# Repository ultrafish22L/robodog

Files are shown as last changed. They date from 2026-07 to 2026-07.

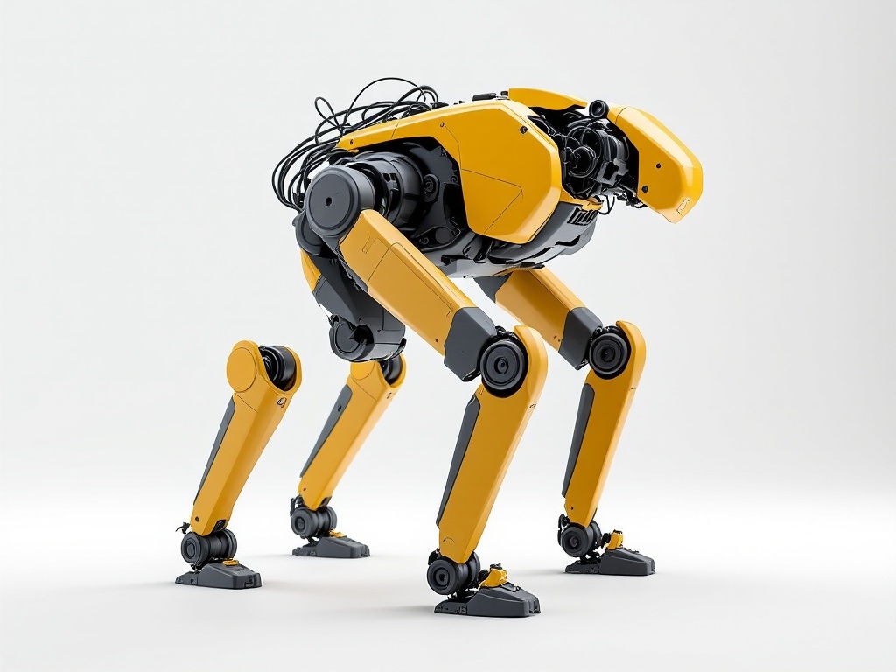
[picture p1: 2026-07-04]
ref/spot_ref_01.jpg

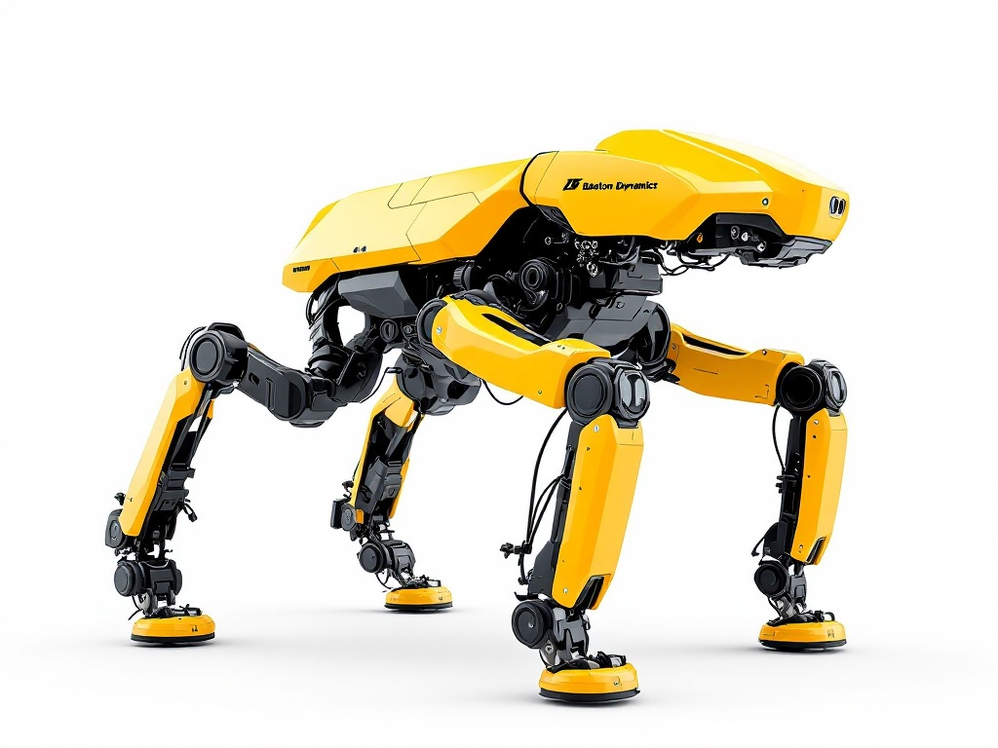
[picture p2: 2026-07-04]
ref/flux_side_b.jpg

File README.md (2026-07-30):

# Robodog — custom 3D-printable micro-servo quadruped

A parametric, 3D-printable quadruped ("Spot-mini") — a **fully custom design** (Boston Dynamics
Spot and the SM3 Spot-Micro were visual **references only**; no external mesh is used). Driven by
**12 micro-servos, 3 per leg** (knee = **MG90S** metal-gear, single-shear; the rest SG90-class).
Geometry is generated in **FreeCAD 1.1** by Python `Part` scripts — there is no saved `.FCStd`;
running the scripts rebuilds and re-exports everything.

> **Status — FIRST PRINTABLE PROTOTYPE (2026-07-30).** The v9 canonical set (11 STLs below) is
> watertight/manifold and slicer-ready for a Bambu **X1C** (256³ bed). See `robodog.md` (design
> bible + session log) for the full history and the latest `### Update`.

## Design (v9)
- **Direct-drive knee** (no linkage): the tibia bolts straight to the knee servo horn. ~200 mm dog,
  frame X ±103 mm.
- **Open truss frame** (`framemin.py`) with a central Y=0 wall, rim rails, 4 corner blocks, and two
  Ø16 splay-pin collars ~3 mm proud fore/aft. Carries the body snaps + alignment pegs.
- **One-piece snap-on body** canopy (`part_body.py`): single-feature head/rump, open belly over the
  trunk, form-fit hip openings, a crown-spine stiffener rib. Held by **lateral detent nubs + vertical
  alignment posts + central-wall pegs + collar-grip rings**.
- **Servo-horn receivers** are embedded (`horns.py`): the **arm** horn is the canonical print — the
  real OEM horn mesh (`servos/hornarm.stl`) is cut into the coxa/femur/tibia so the actual horn
  drops in at a print pause. (`mesh`/`round` variants available via `--horn=`.)
- **Printed screw-in splay pin** (`framemin.py` → `sm3sg90_pin`): Ø7.8 pilot + P2.0 thread mating
  the collar bore + a slotted Ø13 head. Print ×4.

## Canonical print set — 11 STLs (`stl/sm3sg90_*.stl`)
| STL | qty | script | notes |
|---|---|---|---|
| `sm3sg90_v9_frame` | ×1 | `framemin.py` | open truss, ~111 g |
| `sm3sg90_body` | ×1 | `part_body.py` | snap-on canopy |
| `sm3sg90_coxa` + `_mir` | ×2 ea | `coxablock.py` | L/R chiral, arm horn |
| `sm3sg90_coxa_cover` + `_mir` | ×2 ea | `coxablock.py` | femur-hip bearing face |
| `sm3sg90_v9_femur` + `_mir` | ×2 ea | `legflat_v9.py` | arm horn |
| `sm3sg90_v9_tibia` + `_mir` | ×2 ea | `legflat_v9.py` | arm horn, direct-drive |
| `sm3sg90_pin` | ×4 | `framemin.py` | screw-in splay pin |

All rigid PLA/PETG/ASA. **Bought:** 12 micro-servos, 8× 688 + 4× 684 bearings, M2 screws, electronics.

## Build / regenerate
Scripts `exec` each other into shared globals (never `import`). Run **headless** (GUI-independent):
```bash
"C:/Program Files/FreeCAD 1.1/bin/freecadcmd.exe" -c "exec(open('part_body.py').read())"   # coxa+cover+frame+body+pin
"C:/Program Files/FreeCAD 1.1/bin/freecadcmd.exe" -c "exec(open('legflat_v9.py').read())"  # femur+tibia (+mirrors)
```
`part_body.py` chains `dog14.py → dog13.py, coxablock.py, framemin.py, legflat_v9.py`. For the live
assembly view, run `dog14.py` in the FreeCAD GUI (frame + 4 legs + coxae + pins + body). Add
`--horn=mesh|round` to regenerate a horn variant.

## Key files
- **`dog13.py`** + its modules (`dogcommon`, `part_femur`, `part_tibia`, `part_boot`, `part_shoulder`,
  `part_frame`, `part_dummies`) — base geometry, the measured joint/splay axes, servo-mesh cutter.
- **`legflat_v9.py`** (leg, spec `LEG_SPEC.md`), **`coxablock.py`** (coxa, spec `COXA_SPEC.md`),
  **`framemin.py`** (frame + pin), **`part_body.py`** (body), **`horns.py`** (horn receivers),
  **`dog14.py`** (assembly + clearance gates).
- **`control/`** — the all-Python control/sim stack (URDF generated from the CAD axes; PyBullet, gait,
  poses). See `control/README.md`; `robodog.urdf` is regenerated by `control/gen_urdf.py`.
- **`robodog.md`** — the design bible + session log (**read the latest `### Update` to resume**).
- Auto-memory (loaded each session): `~/.claude/projects/C--ultrafish-robodog/memory/`.

## Gotchas (the ones that bite)
- Every printable part must be a **single watertight solid** (single shell for the hollow body — a
  trapped void isn't printable). Re-run the clearance gates after any change.
- STL export via `MeshPart.meshFromShape` (not `Shape.exportStl`); gate on watertight + manifold.
- The full chain in the **GUI exceeds the 90 s MCP RPC cap** (coxablock mesh booleans) — build
  headless via `freecadcmd`, or run `dog14` in the GUI and let the doc finish on the GUI thread.
- `servos/` is large local reference (gitignored) — but `servos/hornarm.stl` is force-tracked because
  `horns.py` reads it at build time.

## Known open items
- Collar grip is a light press (0.2 mm), not a click-into-groove snap — tune if wanted.
- Blade **width** in the arm horn embed and a few servo fits are still bench-verify items.
- `pamphlet.html` / `robodog.pdf` are the **old-design** assembly manual (generator removed) — stale.

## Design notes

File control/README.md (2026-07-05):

# robodog — control software

All-Python control + simulation for the SG90 quadruped, **generated from the CAD** (`../dog13.py`).
Runs headless in [PyBullet]; the same kinematics + gait code is intended to run on a Raspberry Pi +
PCA9685 driving the 12 SG90 servos (sim → real by design — only the bottom driver swaps).

## Setup
```
py -3.13 -m venv .venv
.venv\Scripts\python -m pip install pybullet numpy trimesh pillow
```

## Modules
| file | what |
|---|---|
| `kinematics.py` | per-leg 3-DOF FK/IK in the body frame; anchors (SP/HP/K) come from the CAD. `Leg.ik(target, warm=)` |
| `gen_urdf.py` | writes `robodog.urdf` from the axis constants + the 17 exported STLs + trimesh inertials |
| `poses.py` | named static poses (stand/sit/lie/paw) as body-frame foot targets + a self-collision validator |
| `gait.py` | static **crawl** gait + a PyBullet dynamics runner (`run()`) that measures forward travel + uprightness |
| `explore.py` | random → hill-climb search over gait params, scored by sim rollout; writes `best_gait.json` |
| `viz.py` | load the URDF, verify FK vs kinematics, render poses |

## Quick start
```
.venv\Scripts\python gen_urdf.py     # build robodog.urdf
.venv\Scripts\python viz.py          # FK check + zero/stand renders
.venv\Scripts\python poses.py        # pose library + validation montage
.venv\Scripts\python gait.py         # crawl walk in sim (filmstrip)
.venv\Scripts\python explore.py      # search for a better gait
```

## Verified (2026-07-04)
- Per-leg FK matches PyBullet to 0.00 mm on all 4 legs.
- Poses solve at ~0 mm IK residual; collision validator catches forced self-collisions.
- Crawl gait walks **forward, upright, without falling** under gravity.

## Roadmap
- [x] 1 model + FK/IK  [x] 2 poses + validator  [x] 3 crawl gait  [~] 4 gait search
- [ ] 5 glTF/three.js web viewer  [ ] 6 `hardware.py` — Pi/PCA9685 PWM + servo calibration

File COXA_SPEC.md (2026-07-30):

# COXA SPEC — canonical source of truth

**Read this first before touching the coxa. Edit it IN PLACE** — it is a spec (current state),
not a changelog. Only the short decision log at the bottom records *why*.

Built by `coxablock.py` (subtractive-from-block). Supersedes `dog13.py`'s `shoulder()` **for
printing**; `shoulder()` is still the live `SH` used by the assembly/gates/renders and by
`frameblock.py`, so it stays until coxablock replaces it there too.

---

## Parts — 2 printable, ×2 chirality = 4 STLs in `/stl`

| STL | vol mm³ | role |
|---|---|---|
| `sm3sg90_coxa.stl` + `_mir` | ~18.5k | the **solid block**: servo1 pocket, tab channel, wire slot, splay bearing cup, splay horn — **R17 solid end housings (2026-07-29, un-did the R16 barrel strip; solid walls on the servo ±X faces)** |
| `sm3sg90_coxa_cover.stl` + `_mir` | 4238 | black snap cover: closes the +Y mouth, cages the servo, **is the femur bearing face** (was 5433; shrinks with the seam profile) |

All four (plus the `_spline` pair, coxa 9152) verified on disk: watertight, manifold, no self-intersections —
the export now runs export.py's `repair_clean` write-re-read loop, and the coxa build FAILS (no cover STL)
if the cover diverges from the seam profile.

### Horn variants — 3 modes (`--horn=mesh|round|arm`) via `horns.py` (user 2026-07-28)

The −X splay horn end is built in one of THREE modes via the shared **`horns.py`** (`exec`'d, not imported;
`horn_void(COXA,(hrn_face,SPY,SPZ),(1,0,0),(0,0,1),MODE,floor=0.5,mesh_len=HRN_DT+HRN_ST,m2=None)`). Back-compat:
`embed`→`round`, `spline`→`mesh`. **The COXA alone differs; the cover is horn-independent, exported once (canonical
round run only).** The block genuinely rebuilds per mode (R_END + the chamfer envelope depend on the horn footprint).

| mode | what the −X horn end gets | STL names |
|---|---|---|
| `round` (canonical) | O20 disc chamber (1.5) + O7 spline hole + roof (**3.5mm WSRV wall**) — OEM round horn dropped in at a print pause | `sm3sg90_coxa[_mir].stl` — the **canonical** names |
| `mesh` | printed 23T female spline (prints in place, no hardware) | `sm3sg90_coxa_mesh[_mir].stl` |
| `arm` | O7.6 hub pocket (4.25) + arm through-slot (12.5, ±Z so it clears the cover seam) + roof (1.75mm to servo1); M2=None (would breach servo1) | `sm3sg90_coxa_arm[_mir].stl` |

- **PAUSE-LAYER (embed): −X face DOWN on the bed, pause at 0.5mm** (round: at the disc-chamber floor / arm: at the
  arm-slot shelf), drop the OEM horn hub-down, resume — the WSRV wall roof captures it.
- `round` (canonical) must keep the exact filenames: **`control/gen_urdf.py` requires `stl/sm3sg90_coxa_mir.stl`**.
  `mesh`/`arm` write suffixed alongside. Verified watertight/manifold/1-solid + adversarial-clean (wf_6e2a558c).
- The receiver is **parametric, not a mesh**. A donor STL (`MicroServo_9g_Gear_Base_V4`) was tried and
  abandoned: `makeShapeFromMesh` gives one face per facet, and at 1448 facets the fuse ran >196 s and
  timed out the GUI. Decimating to 970 facets **inverted the normals** (negative volume → fused to
  nothing); harmonising fixed the sign but left 6% of the volume with the teeth gone. Parametric teeth
  build in ~40 s and are exact. Do not reach for the mesh again.
- **`SPL_TEETH = 23` must equal the real servo's spline** (user, 2026-07-19). ⚠ At 23T the teeth are
  ~0.32 mm wide × 0.25 mm deep, **under a 0.4 mm nozzle** — dimensional match was chosen over
  printability, and this variant is UNTESTED on the printer. `embed` remains the default for a reason;
  LEG_SPEC's v7 audit found a printed spline cannot drive a real servo.

There was a third part — `sm3sg90_coxa_insert.stl`, the yellow slip-fit femur ring — **deleted 2026-07-19**
(decision log R8). coxablock now also **removes any stale insert STL from `/stl`** on each run, so a
retired part cannot linger in the slicer set.

Both: **valid, single solid**. Mirrors are reflected about **each part's own bbox centre** —
that is `gen_urdf.mesh_world_placement`'s contract (it then applies `T(0,-2c,0)`). Mirror export is
validity-gated: a mirror is only written if `isValid() and solids==1 and vol==orig`.

## Axes — MEASURED, never idealised

Both hip axes come from the **scanned** servo meshes via `dogcommon.spline_axis()`, never from the
idealised boss cylinders (on the EXI-style case the spline is **not** centred in the bulky top block,
so those bosses sit 0.398 low).

- splay (X) axis @ `(y 20.0, z 10.3984)` = `SPY, SPZ`
- hip-pitch (Y) axis @ `z 10.3984` = `HPZ`
- **skew 0.0000** — the two axes intersect, i.e. a proper 2-DOF hip. (They were 2 mm skew before 2026-07-19.)
- `S0DZ = -2.000` drops the servo0 pocket so servo0's spline lands on the splay axis.

## Block

- extents `X[93.0,119.9] Y[4.7,31.0] Z[-16.8,26.1]`, **2 mm wall**, front +Y **open** at y=31.0
- back wall **2.0 mm** (`BACK=WALL`) — the face opposite the clip is pulled in as far as the minimum
  wall allows. This is the binding constraint on the big chamfers; see Edges.
- servo1 pocket cut with the **scanned mesh** (`servo_cut("s1")`), front-insert, +0.25 mm/side
- **`POCKD = 1.5`** extra pocket depth: a pure relief cut (`PDEEP`) behind the scanned servo body, so the
  pocket floor sits at y 6.72 instead of 8.22. It does **not** move the servo datum — `SPY`/`SPZ` stay put;
  it only lets the servo sit 1.5 mm deeper. `by0 = sb.YMin - POCKD - BACK`, so the back face follows the
  floor out to y 4.72 automatically and the 2.0 wall is preserved.
- ⚠ `PDEEP` is sized from **`sbody`** — the servo BODY cross-section sampled at the servo's back face
  (`S1.common(<1 mm slab at sb.YMin>)`, 13.00 × **23.25**) — **not** from `sb`. `sb` is the bbox of the whole
  scanned mesh and its Z span (**32.96**) is the MOUNTING-TAB span; the tabs sit at the FRONT (`y>=24.58`),
  while at the pocket floor the servo is only its base. Sizing the relief from `sb` gouged it 9.71 mm taller
  than the base over the full 1.5 mm depth — a gap at the bottom of the pocket shaped like the tabs. See
  decision log R9. The `feats` chamfer-clearance envelope carries the same split: tab-height servo box +
  a separate base-height box for the deepened region.
- tabs at `Y>=24.6` → front channel `Z[-11.9,21.2]` clears them
- wire slot 4 mm wide `X[104.0,108.0]`, `Y[9.2 → 31.0 face]`, down to `Z10.3` (past the wire nub)

## Splay end (+X) and horn end (−X)

- **SOLID SQUARE END HOUSINGS (R17, 2026-07-29)** — the R16 barrel strip-to-minimum was REMOVED. It cut
  everything outside a `R_END≈12.6` cylinder from the two end bands, trimming both WSRV=3.5 servo-face walls
  to a Ø25.2 disc and opening the servo ±X faces as windows + freestanding webs (user: *"no actual wall
  against the side of the servo, lots of free standing flimsy walls"*). Now COXA is the **full solid block**
  cut only by its functional pockets, so a **solid 3.5 mm wall bears directly on the servo's bearing(+X) and
  spline/horn(−X) long faces**; the bearing cup + horn disk/spline are blind bores INTO the solid ends. Chamfer
  dropped 6→3 (`CHAMF_MIN` raised to 3 so the tight back-wall edge stays sharp, not a corrupting sliver).
  COXA vol ~9047(R15)→10307(R16 stripped)→**~18.5k (solid)**. The mid band still carries servo pocket, snap-hook
  corridor, wire slot, seam. **Export note:** the full-length solid ends tessellate with corrupt-chamfer boundary
  dropouts that FreeCAD's `hasNonManifolds()` misses; `_repair_clean` now `fillupHoles()` **last** → watertight/
  manifold/1-solid, valid volume (trimesh-verified; FreeCAD's residual self-int flag on the coplanar fills is
  benign → label "sealed"). The lofted cover re-matches the fuller seam automatically.
- **`WSRV=3.5`** (was 2.0, user 2026-07-29 "servo long-face walls too thin"): the wall on **each** servo long
  face (−X horn side + +X bearing side). Block X width **26.9 → 30.0** (+3mm splay span); hrn_face 92.95→**91.45**,
  bearing/block +X out +1.5. **The frame follows automatically** (pocket grown from COXA; splay pin from `brg_x0`)
  EXCEPT servo0, which `framemin` now tracks via `DHORN = 92.95 - hrn_face` (shift servo0 + pocket −X so the splay
  spline stays engaged, foot/URDF unchanged). All X coords below are the OLD WSRV=2.0 values → add the shift.
- **bearing** 688 Ø15.94 × 5.4, cup open on +X, wall to servo **3.5**
- **crush ribs** on the cup lead-in stand **0.10 proud** — see trap #1
- **horn** (−X): disk Ø20.0 × 1.5, fully enclosed (wall to servo **3.5**);
  spline Ø7.0 × 3.0 protruding. Print-in-place via pause-drop (worked in PLA).

## Cover (CLIP)

- flat cover `Y[31.0,35.1]`; **built in BOTH horn modes** (its hook pockets shape the COXA — skipping it
  desyncs the variants) **but exported only by `embed`**: the GEAR fuse perturbs the edge passes enough
  that the two "identical" covers differ, and only the embed one tessellates watertight (R16).
- the seam profile is the **fused whole seam REGION** (0.2 slab + mouth/notch patch solids → single +Y
  face → OuterWire), not the largest front-face fragment — since the end trims the front face is
  fragmented, and the largest piece is a bearing-end patch, not the silhouette. The seam check is FATAL:
  a diverging cover never reaches `/stl`.
- the **bottom snap hook fuses unfilleted** — its rounded variant tessellates self-intersecting slivers at
  the gusset root corners (the same fuse that flips the BREP invalid), which mesh repair could only clear
  by punching holes. Top hook keeps the rounding.
- **no inner-face pocket**: with the `BEAR_OD` disk, tab roots and hook bands kept solid, a 2 mm-wall
  pocket only reaches ~0.2 g of material, and its walls graze the end arcs tangentially (self-x again).
  The cover's strip is the profile shrink it inherits from the coxa end trim (5433 → 4238).
- **FLUSH** chunky snap: 3.5 mm beam ×14, recessed flush (block grew `CLIPGROW=3.0`/side,
  wall-to-servo 1.50) + flush lateral gusset +3.0/side; leg 6.1 mm deep × 3.5 thick, nub r1.0;
  2-tab retention, tabs → `Y27.1`. Strain 0.98 %, no thin parts.
- output opening = rounded-rect **MEASURED off the servo's top block**, not hardcoded: sample the servo
  across the cover's Y band (skipping the first 0.3 mm, where the section is still the servo BODY
  13.00 × 23.25) → top block **11.96 × 14.56**, grown by `OPEN_CLR = 1.0`/side → **13.96 × 16.56 r3**.
  Centred on the **BLOCK** (105.95, 8.99), *not* on the spline — the spline sits 1.41 mm above the block
  centre, so the old spline-centred 15 × 18 left only **0.31 mm** clearance at the bottom and 3.13 at the
  top. Now 1.00 mm all four sides; `CLIP ∩ servo1 = 0`.
- **silhouette matches the body exactly**, by construction rather than by re-deriving edges: slice COXA in
  a thin slab at the seam, fuse the two hook *cutters* (the same `g=0.35` that made the rebates) to fill
  the rebate notches back in, extrude that profile forward and cut away everything in the cover's Y band
  outside it. The cover was previously built from the **largest fragment** of the coxa +Y face — the snap
  rebates split that face — then squared back up with a butt box and two square trims, so it came out as
  the raw block rectangle (CLIP Z[−16.83, 26.13] vs the coxa front face Z[−15.33, 26.04]).
  The cut is confined to `y >= FRONT` so the snap arms behind the seam are untouched; an earlier attempt
  clipped the cover over its whole Y range and fragmented it into 5 solids.
  Verified: **0.000 mm³** of cover material outside the coxa profile, and the top-edge X-extents agree with
  COXA at every z (96.26/115.45 at z 25.93 → 92.95/118.85 at z 22.13), i.e. the chamfer taper carries
  across the seam. It also narrows the finger/gusset top where it overhung the chamfer — what the user
  asked for, and desirable anyway since a proud corner there has nothing to grip.
- ⚠ Naming trap: `_slab` is the **hook-builder helper**. Shadowing it with a solid makes `_hook()` raise
  `'Part.Solid' object is not callable` from a frame that points at `_hook`, not at the shadowing line.

## Femur bearing face (was the ring insert)

- **no separate insert**: the femur runs directly on the cover's own flat outer face at `FACE_OUT`.
- `BEAR_OD = 24.0` — the disk around the output opening kept **solid** (excluded from the hollowing
  cut) so the femur bears on solid material, not on the `CWALL` 1.6 shell. It is the only surviving
  trace of the old ring and it still drives the edge-rounding guard.
- Measured: **4.12 mm** of solid backing clear of the servo footprint, **3.52 mm** over it (the `SKIM = 0.6`
  servo-top relief). The old build had only ~1.52 mm of backing plus a loose 1.5 mm proud ring.
- The servo-top relief is cut with the **scanned servo itself** (`S1`, already grown `SCLR`/side) restricted
  to the skim band — exactly "as wide as the servo" and nothing more (**104 mm³**). It used to be a box
  `sb.XLength+2 × sb.ZLength` = 15.00 × **32.96** = 296.6 mm³: 2 mm too wide *and* the full MOUNTING-TAB
  span, though the tabs are nowhere near this plane. Same `sb`-vs-body error as `PDEEP` (R9).
- ⚠ The femur's rub plane moved **1.5 mm inboard** — it used to sit on the ring's proud rim at
  `FACE_OUT + 1.5`, it now sits on the cover face at `FACE_OUT`. Nothing in the repo consumed that
  standoff, but it is a real change to the leg's Y datum: check it at assembly.
- Trade-off accepted: the ring was a swappable wear part and a thrust-washer seat. PLA now rubs
  directly on PLA. If drag or wear is a problem, the fix is a counterbore in the cover for a hobby
  thrust washer — not a return to the loose ring.

## Edges

`CHAMF = 6.0` on every outer **block** edge that has the clearance headroom, then a **graded
fallback** giving each remaining non-clip edge the largest chamfer it can take (quantised to 0.5),
then `ROUND = 1.0` fillet on the remaining exterior edges. `CLR = 2.0` min wall to any internal feature.

- The **+Y clip-mating face is entirely sharp** — `on_front` guards *both* the chamfer and the fillet
  pass. A chamfer there would open a gap under the cover and make one clip edge differ from its
  neighbours. Its only non-flat neighbours are pre-existing horn/bearing pocket walls (79.3deg off Y,
  |ny|=0.186 — steep walls, NOT bevels) and the terminations of fillets on adjacent non-clip edges.
- **Zero** non-clip block edges are left sharp — verified by re-deriving the sharp set from the finished
  solid after the pass, not by trusting the pass's own report.
- The graded pass runs as a **sweep (up to 4 rounds)**, re-deriving its target set from the *current* solid
  each round and stopping when a round chamfers nothing. One pass is not enough: chamfering an edge
  **shortens the edges it meets**, so their centres of mass move and `edge_op`'s per-edge re-find (which
  matches on the centre captured before the batch, tolerance 1e-4) silently skips them. See trap #6 and
  decision log R11. The printed tally reports what was actually cut across all rounds, not round 1.
- `BACK` and `CHAMF` compete for the same material: at `BACK=2.0` the back edges sit close to the
  CLR-grown envelope, so they grade down (5.0 x4, 4.0 x1, 3.0 x2, 2.0 x1) rather than take the full 6.0.
  Restoring `BACK=8.0` would let everything take 6.0 but costs 6 mm of depth. Depth won, by decision R6.
- The horn pocket is grown by **`HORN_CLR = 0.6`**, not the global `CLR = 2.0` (decision R13). At the
  full `CLR` the Ø20 disk crowded the −X end and starved ONE side bevel to 3.5 while its neighbours ran
  at 6.0. The pocket is a captive drop-in for an OEM horn, not a cavity the chamfer can breach, so it
  does not need the full wall. The disk is recessed 3 mm behind the face, so the 45° chamfer stops at
  z 23.13 vs disk top 20.4 — the pocket roof survives.

## Clearances — expected values, do not re-hunt

- `COXA ∩ servo1 = 28.18 mm³` in **both** horn modes — **scan noise, not a breach.** `S1` is a scanned
  mesh with ~0.2–0.3 mm surface noise, so `common()` against a clean BRep always leaves slivers wherever
  a face runs at nominal clearance. Measured: **4 disjoint solids, mean thickness 0.267 mm**, sitting
  exactly on the Ø13 output-slot footprint. A real interference is ONE contiguous solid with depth.
- The build therefore asserts on **depth, not volume**: `SERVO_CLR_TOL = 0.35` mm per solid. Exact zero
  is unachievable against a scan — an earlier 0.000 reading was luck, and chasing it back cost two wrong
  "fixes" (see R13). If this ever trips, measure the intersection **bbox and solid count** before
  changing any geometry: a number without its shape is not evidence.
- `COXA ∩ servo1 pocket wall = 0` where it matters; horn disk 5.73 mm to block top, bearing cup 7.76.

## OPEN

1. **Re-print the set in PLA** (3rd attempt) — now only 2 parts. Confirm the flush chunky clips survive
   support removal, and check how the femur runs on the bare cover face (drag, wear, slop) now that the
   ring is gone. Dial fits from there.
2. ~~`RING ∩ CLIP ≈ 37 mm³`~~ — moot: retired with the ring (R8).
3. Eventually retire `dog13.shoulder()` in favour of this block.
4. The two `/stl/*.3mf` slicer projects (`sm3sg90_coxa.3mf`, `sm3sg90_coxablock.3mf`) predate R7/R8 and
   still contain the insert. They are the user's slicer files, not build output, so coxablock does not
   touch them — **re-import the STLs before the next print.**
5. **Dead-code sweep is INCOMPLETE.** R10 asked for "clean it all up, remove old dead code". Done by hand:
   stale file header, the superseded SIMPLE-HOOK-CLIP and MATCHING-CHAMFER comment blocks, the ring-deletion
   parenthetical, the unused `shape` param on `_oplane`, the duplicated `earY` probe, and the boss-walk
   (now `_boss_top()`, so its six scratch shapes stop leaking into the shared session globals). An
   exhaustive multi-lens audit was launched but was killed before producing findings — **it has NOT run**,
   so more dead code may remain. Resume it, or re-audit, before treating this as closed.

---

## Traps — do not relearn

1. **Never key "is this an outer face" off a live `BoundBox`.** `_oplane()` used to compare against
   `shape.BoundBox`; the +X cup crush-rib lead-in stands 0.10 proud, so `XMax` read 119.95 while the
   +X face sits at 119.85 — past the 0.06 tolerance. The **whole +X face** therefore failed the test,
   every edge on it was invisible to `blk_edges`, and the back came out chamfered on 3 sides and sharp
   on the 4th. Fix: test against the **block extents** (`bx0..bz1`), which are design intent and don't drift.
2. `makeFillet` / `makeChamfer` / `fuse` can **"succeed" yet return an INVALID spike that silently
   drops geometry**. Validate every edge op (`isValid` / `Solids` / `Volume`) and revert to the
   pre-op solid. All edge ops go through the guarded `edge_op()` helper.
3. FreeCAD's **self-intersection remover HANGS** — avoid it. `.fix()` (ShapeFix) repairs the hollow
   cover BREP fast and is the right tool.
4. The **EXI S1123 has a bulkier top block than a stock SG90** (confirmed by photo + scan). Anything
   sized to the SG90 taper will foul it.
5. `servo_cut("s0")` is built in the FRAME's **post-yshift** y; `servo_cut("s1"/"s2")` are **pre-yout**.
   coxablock works pre-yout → subtract `YSHIFT` for s0 only.
6. **`edge_op`'s per-edge fallback re-finds edges by a CenterOfMass captured BEFORE the batch.** Chamfering
   an edge shortens its neighbours, moving their centres, so those neighbours miss the 1e-4 match and are
   **silently skipped — the pass still reports success**. Any caller that chamfers a set of mutually
   adjacent edges must sweep (re-derive the target set from the current solid and repeat) rather than
   trusting one pass. Corollary: **verify edge passes by re-measuring the finished solid**, never by the
   pass's own log.

## Decision log (why only — never live values)

- **R17 (2026-07-29)** — user: *"there's still no actual wall against the side of the servo on the sides with
  bearing and spline receiver, just build a wall right into them… much closer to what we had before all the
  recent 'optimizations'… lots of free standing flimsy walls."* **Reverted R16's barrel strip** (the root cause:
  R_END trimmed the servo-face walls to a Ø25.2 disc, opening windows). COXA is now the full solid block; solid
  3.5 mm walls bear on the servo bearing(+X) + spline(−X) faces. Prior in the same session: WSRV 2→3.5 widened
  both walls (frame servo0 tracks via `DHORN`); CHAMF 6→3. Two implementation notes: (1) `CHAMF_MIN`→3 leaves the
  tight back edge sharp (the graded sliver-chamfer was NOT the mesh corruption, but sharp = more solid = on-intent);
  (2) the real corruption is corrupt-chamfer boundary dropouts on the full-length ends that FreeCAD's manifold
  check misses — `_repair_clean` now `fillupHoles()` last (trimesh `is_volume` confirms a valid solid; the
  cover auto-follows). Verified: 8/8 STLs watertight/manifold/1-solid, frame + working-range gates 0.

- **R16 (2026-07-22)** — user: *"strip coxa to absolute minimum, everything needs 2mm walls though"* —
  supersedes R15's "unchanged" (the *interfaces* still don't rescale; the *mass* does). COXA 15667 → 9047
  (−42%), cover 5433 → 4238, whole set −37%. One cut idea carries it: the end housings only need
  `feature radius + 2 mm` of meat about the splay axis, so both ends become r 12.6 barrels; the mid band
  (servo, hooks, wire, seam) keeps the full profile. Three defects surfaced and fixed on the way:
  (a) the trim **fragments the front face**, and the cover lofted from the largest fragment = a
  bearing-end patch — caught by the seam check, which was print-only and let the bad cover export; it is
  now **fatal**, and the profile comes from the fused seam region. (b) the cover meshes were
  **self-intersecting on disk** (latent — coxablock never ran export.py's repair loop): repair alone
  "fixed" them by punching holes, the real cause was the **bottom hook's fillet** slivering at the gusset
  roots → bottom hook now fuses unfilleted, export runs `repair_clean`, and the on-disk set is verified
  watertight. (c) a cover inner-face pocket was tried and REMOVED — 0.2 g of reachable material wasn't
  worth tangent-grazing the end arcs. Also: only `embed` exports the cover now — the spline run's subtly
  different rebuild used to clobber the canonical file.
- **R15 (2026-07-21)** — **coxa carries over UNCHANGED into v9** (the 200 mm / 0.82× robot). Every coxa
  dimension is bound by things that don't scale with frame length: the servo1/servo2 envelopes, the 6804
  bearing, the splay travel, and the horn interface. The v9 frame (`framemin.py`) cuts its corner pockets
  from the *live* coxa geometry (swept-bbox + the same clearances as frameblock), so fit at the new
  wheelbase is by construction, not by rescale. No `sm3sg90_v9_coxa` set exists on purpose — the v29-era
  `sm3sg90_coxa*` STLs remain the current parts.
- **R14 (2026-07-19)** — **horn variants split out**, selected by `--horn=embed|spline`. The user wants
  both a build where an OEM horn is embedded at print time and one where the spline is printed, without
  maintaining two scripts. Only the COXA differs, so only it carries a suffix; `embed` keeps the
  canonical names because `gen_urdf` hardcodes `sm3sg90_coxa_mir.stl`. Tooth count was forced to **23 to
  match the real servo** on the user's instruction, over my objection that 0.32 mm teeth are below a
  0.4 mm nozzle — dimensional fidelity was the explicit priority; printability is untested.
- **R13 (2026-07-19)** — user: *"the 1 side bevel that is narrower than the rest should match"*. Fixed by
  growing the horn pocket with `HORN_CLR = 0.6` instead of `CLR = 2.0`. Logged mainly for the **debugging
  failure that followed**: a `COXA ∩ servo1 = 28.18 mm³` reading was blamed on the spline receiver, then
  on this bevel change, and I twice proposed "fixing" working geometry — including detuning this very
  bevel back. The user checked the model and said plainly there was no interference. Measuring the
  intersection's **bbox and solid count** settled it in one call: 4 disjoint 0.27 mm slivers on the slot
  footprint = scan noise. The check now asserts on depth with a tolerance. **Lesson: a volume with no
  shape is not evidence — measure the shape before touching geometry, and prefer the user's read of the
  model over a bare number** (cf. [[mechanical-design-conceptual]]).
- **R12 (2026-07-19)** — cover output slot changed from a full-radius **obround** to a **rounded rect,
  `SLOT_R = 4.0`**, on user request. Flat top/bottom edges hand back the four corners as bearing face
  (+54 mm³). The Ø12 boss still clears: nearest approach into a corner quadrant is 2.96 from the arc
  centre, i.e. 1.04 inside the R4 arc.
- **R1–R2** — first two PLA fails drove the CHUNKY flush clip (3.5 mm finger, proud 0) and the
  rounded-rect cover opening: the EXI's top block is bigger than the SG90's, and the old press-fit
  round washer wouldn't seat, hence the slip-fit ring.
- **R3** — flush clips + boolean-robustness guards after a bottom-hook fillet silently dropped geometry.
- **R4** — even chamfers: one uniform `CHAMF`/`ROUND` via the shared guarded `edge_op`, replacing a
  ragged per-edge clearance-scaled scheme (chamfers 2..11, fillets 0.5..3) that made the back look uneven.
- **R5 (2026-07-19)** — re-datumed horn socket / bearing cup / cover opening / femur ring onto the
  **measured servo1 spline**, which also made the splay and hip-pitch axes intersect; fixed the
  `_oplane` bbox-drift trap (trap #1); added the validity-gated L/R mirrors, which unblocked
  `control/robodog.urdf` regeneration (it had been stranded on the old z=12 splay datum).
- **R7 (2026-07-19)** — user asked for a cover chamfer matching the body, plus 1.5 mm more pocket depth
  ("which moves the back out 1.5mm too" — correct, `by0` is derived from the pocket floor). The first
  cover attempt cut the whole silhouette complement and fragmented the part; the user's own diagnosis
  ("narrow the clip's wide finger top to clear the chamfer") was the fix — measurement confirmed the
  finger ran the full block width at the top, so four local corner wedges both chamfer the cover and
  narrow the finger. `POCKD` is deliberately a relief cut, so the measured servo datum does not move.
- **R11 (2026-07-19)** — a plain run of coxablock showed **3 back-face edges still sharp** although this spec
  claimed zero, and the graded-chamfer pass had reported success. Root cause was trap #6: the pass captured
  edge centres up front, chamfering shortened the neighbouring edges, and the per-edge re-find then missed
  them without raising. Fixed by sweeping the graded pass until a round changes nothing (0 sharp edges now,
  COXA 15252 → 14985 mm³ as the three edges finally took their 3.0/2.0/3.0 chamfers). The pass's tally was
  also corrected to report edges actually cut rather than the round-1 snapshot — a log that overstates what
  it did is the same class of defect as the bug itself.
- **R10 (2026-07-19)** — user: *"top of clip profile doesn't match coxa and cutout in clip is too wide, only
  should be as wide as the servo. clean it all up remove old dead code"*. Three findings: (a) the cover was
  built from only the **largest fragment** of the coxa front face, so R7's corner-wedge chamfer was patching
  a symptom — replaced with an exact silhouette clip taken from the body itself; (b) **both** cover cutouts
  were oversized in the same way `PDEEP` had been — the skim relief from `sb`'s tab span, the output opening
  hardcoded and centred on the spline instead of the top block. Both are now measured off the scan.
  (c) Cleanup was **partial** — see OPEN item 5.
- **R9 (2026-07-19)** — user: *"the extra space at the bottom of the servo pocket is too wide, it should match
  the base of the servo not the tabs"*. Correct: the R7 `POCKD` relief was built from `sb`, whose Z span is the
  TAB span, so the deepened floor was cut 9.71 mm taller than the servo base. Fixed by sampling the body at the
  servo's back face (`sbody`). Verified: the two slivers the old relief gouged (above/below the base, 96.1 mm³
  each) are now 100 % solid, and COXA grew 15059 → 15252 mm³ = the 192 mm³ restored.
- **R6 (2026-07-19)** — user asked for: no chamfer on the clip-mating face with all clip edges matching;
  even ~6 mm chamfers on all non-clip edges; and the face opposite the clip moved in as far as possible.
  The last two compete for the same material, so the trade-off was put to the user, who chose **depth**:
  `BACK` 8.0 -> 2.0 (COXA 21525 -> 14490 mm3, -33 %), with the back/top/bottom chamfers grading down
  instead of being silently skipped, so nothing non-clip is left sharp.

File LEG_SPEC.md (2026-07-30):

# robodog LEG — canonical design spec (single source of truth)

> Read this FIRST before any leg work. Edit lines **in place** when a decision changes — this is a
> spec, not a changelog. The build script's header must mirror this file; if they disagree, this wins.
> Spec version: **v9 · updated 2026-07-27** (direct-drive knee, 0.82× scale, body-through-slot + tab-flat
> mount, mode-consistent knee interface, horn variants).
> Live script: **`legflat_v9.py`** (STLs `sm3sg90_v9_*`). v8 (`legflat_v8.py`, reducing-lever knee) is
> preserved on disk but superseded.

## System (3-DOF leg, SG90-class servos ~22.7×12.1×22.5 mm; some are EXI S1123, bulkier top)
- **servo1 = frame → splay** (hip abduction).
- **servo2 = coxa → hip pitch** (femur swings fore/aft), direct-drive.
- **servo3 = on the femur → knee, DIRECT-DRIVE 1:1** (v9 dropped v8's crank/pushrod/kneecap-lever/688/Ø8-pin
  — halving the moving-part count is the lightness win). It lies flat along the **lower femur** (long axis
  down the thigh ∥ Z), body **outboard** of the femur plate, **output spline pokes laterally INBOARD (−Y) at the
  knee** (servo FLIPPED 2026-07-22; only the body stays outboard); the tibia mounts on its horn from the inside.

## Bones — 0.82× scale, Spot/Unitree proportions kept
- Femur + tibia = flat **7 mm plates** (thin dim = lateral Y), curved sagittal profiles + racetrack
  lightening slots. `BONE=7.0`.
- **Femur 70 mm : tibia 80 mm ≈ 0.87:1** (Spot ratio held through the 245→200 frame scale-down).
- Tibia shin symmetric about x=106, tapering ≈18 → 10 mm; toe arc r4.5. All bores centered on x=106.

## KNEE — direct drive, single-shear on a MANDATORY MG90S
- **The servo3 output boss lands ON the knee axis (XC, KZ)** — `place_servo` seats the boss on the axis via
  `BOSS_DZ`=−5.62 (the boss's Z-offset from the servo CENTRE, measured off the mesh), after `rotate(Y,90)`+
  `rotate(Z,180)`. Before the 2026-07-22 fix the output sat ~18 mm off the knee = the tibia could not be driven.
  The tibia head is INBOARD (Y 28.7–35.7) and the servo body is outboard, so the spline reaches inboard to the tibia.
- Knee load is carried by the **servo output shaft alone (single-shear)** — lightest possible, no separate knee
  bearing/pin. A printed inboard double-shear stub was built and REMOVED (audit 2026-07-27: PLA-on-PLA journal +
  thin bridges = a fresh failure point). Therefore **MG90S (metal gears + output bushing) is MANDATORY at the
  knee, not optional** — the metal output IS the bearing (user decision 2026-07-27).
- **Torque budget is the crux** (this reverses the v8 lever the v7 audit demanded — accepted at the new
  scale): ~0.15 N·m trot-hold vs SG90 stall 0.176 (≈85%, runs hot) / **MG90S 0.216 (≈69%, ok)**. Static
  stand ≈35%. → **recommend MG90S metal-output at the knee**; keep gaits tucked. This is the proven
  cheap-SG90-quadruped formula — it works *because* the dog is small and light.
- Travel **0–70°**, foot swings rear (−X)/up (+Z); collision sweep asserts 0 mm³ over the range.
- Servo output clearance: Ø6.8 bore through the femur plate at K (the shaft passes the plate; the plate
  does NOT bear on it).

## Servo3 mount — body-through-SLOT + offset TAB FLATS (tibia on the inside)
- **servo3 output points INBOARD (−Y)** (user 2026-07-22 flip): `place_servo` does `rotate(Y,90)` then
  `rotate(Z,180)`; the spline tip (bbox YMin) seats 2 mm inboard of the femur inner face (`FIY0`−2), boss on
  the knee axis via `BOSS_DZ`=−5.62. Only the **servo body sticks out outboard** (to Y≈64) → clean outboard
  profile; the **tibia tucks on the INSIDE** against the femur inner face.
- The femur mount (user 2026-07-28 rev: "cap the top, only opening = spline side it's inserted from"):
  a **CLOSED body pocket with a CAPPED TOP** — a housing wraps the servo BODY on ±X, outboard +Y, bottom −Z **and
  the top +Z (2 mm cap)**. The **ONLY opening is the inboard −Y (spline/tibia) face**: the servo slides in
  **LATERALLY** from there, its output spline pokes −Y to the tibia, and the **tibia + M2 centre screw cap the −Y
  opening = retention**. Above the servo the thigh reverts to **SOLID plate** up to the hip. Walls **2.0 mm** all
  round (W=2.6, CLR=0.6; audit 2026-07-28 fixed the old 0.4–1.4 mm walls + 2.15 mm gutted rails → closed box + 3.4 mm
  rails). `servo_mount()`; `FEMUR∩servo3(0.5-clr)=5.1` (real body 3.2, sliver). Femur ≈ **18.3k mm³** (closed box).

## Interfaces
- **Servo horn receiver = 3 modes (mesh / round / arm) via `horns.py`** (user 2026-07-28: "all servo receivers need
  3 ways to print"; **exec `horns.py`, don't import**). `horn_void(part, P, D, A, mode, floor, mesh_len, m2, rnd_disk,
  slot)`: P=mating face, D=into-part axis, A=arm axis. **mesh** = printed 23T female spline (no hardware). **round** =
  OEM round disc embedded at a print pause (bones use **O14** so it fits the O20 boss with a roof; O7 hole + 1.5
  chamber + roof). **arm** (leg CANONICAL = `sm3sg90_v9_*` names) = OEM single-arm horn embedded: hub **O7.3×4.25** +
  arm **12.5** (user-measured), blade **5.0×1.6 ASSUMED** (slot 5.3×1.75 — bench-verify the real blade, it is the
  torque path). Bones pass **`slot='down'`** (single-sided −Z, arm points down the bone → no flange-top notch).
  HIP: `horn_void(FE0,(XC,FIY0-3,HIPZ),+Y,+Z,mode,floor=1.0,mesh_len=5.0,m2=2.7,rnd_disk=14,slot='down')`.
  KNEE: `horn_void(TI0,(XC,TIY1,KZ),-Y,+Z,mode,floor=0.4,mesh_len=2.0,m2=None,rnd_disk=14,slot='down')`.
  Export builds the blank ONCE, applies all 3 → 12 leg STLs (canonical no-suffix = arm; `_mesh`, `_round`). All
  watertight/manifold/1-solid; adversarial-verify clean (wf_6e2a558c). **PAUSE-LAYER (embed): femur 1.0mm (inboard
  face down), tibia 0.4mm (outboard face down); coxa 0.5mm (−X down). Frame + covers = no pause.**
- **Knee engagement (arm/embed): only ~1.3 mm spline grip** on the loaded knee (thin tibia + ~2mm SG90 spline); the
  **M2 centre screw carries pull-off** as designed — watch it. Fallbacks: tibia `round`, or a knee bolt-through.
- (KNOWN mesh caveats, unfixed — arm is what ships: tibia mesh has ~1.16mm³ servo-boss interference (needs the O7.3
  counterbore round/arm have); 23T printed spline may not press onto a real 20–21T SG90 output.)
  The **M2 centre screw** (O2.7 clearance bore) through the head into the output boss clamps the tibia axially onto
  it — it, not the shallow spline, carries pull-off. M2 self-taps into the SG90/MG90S boss; **M2.5 would split the
  O4.9 boss** (code comment + audit 2026-07-27). It is a **running-clearance coupling** (bore 0.1 mm over the shaft,
  teeth nest) so `common()=0` is CORRECT, not a gap. Tibia face 0.3 mm off the case = max grip.
- Both hip AND knee take the **`--horn=embed | spline`** switch (whole leg is horn-consistent).
- **embed** (default) = OEM SG90 cross-horn capture + M2 centre screw; canonical STL names
  (`sm3sg90_v9_{femur,tibia}[_mir]`). CONTROL STACK REGENERATED from v9/dog14 (2026-07-28): `kinematics.py`
  now SP(0,27.2,10.398)/HP(82.65,0,10.398)/K(82.65,0,-59.602) femur 70, positive-knee flex (0-70), foot0 from
  the v9 ball foot (-150.6); `gen_urdf.py` points at `sm3sg90_v9_{frame,femur,tibia}[_mir]`+`sm3sg90_coxa[_mir]`
  +cover, single tibia (no front/rear split, no boot), and applies the T_COXA/T_LEG raw->body shift +
  convention-agnostic mirror-plane; `robodog.urdf` loads clean in PyBullet, all 4 corners' meshes align to the
  FK feet to 0.000 mm. Regen after any CAD change: `scratchpad/dump_v9_axes.py` -> update the 5 constants -> rerun gen_urdf.
- **spline** = printed **23T female spline** receiver (SPL_MAJOR 4.9 / SPL_ROOT 4.4 / SPL_TCLR 0.10, teeth
  ≈0.32 mm — below a 0.4 nozzle, print-unproven; user's explicit priority). Files get a `_spline` suffix and
  coexist in `/stl`. Params MUST stay equal to `coxablock.py`'s.

## Hip mount (femur ↔ coxa) — VERIFIED same x-z frame
- Coxa hip-pitch servo output axis = **X=106, Z=10.3984, +Y** (`dogcommon.spline_axis("s1")`) = femur hip.
  `legflat_v9.py` builds at nominal `HIPZ=10.0` and applies a **rigid `HPDZ=0.3984` lift at export** (same
  contract as v8): translating the whole chain keeps every bone shape bit-identical, whereas re-datuming
  `HIPZ` would deform the profile. Keep `HPDZ` equal to `dog13.HPDZ`.
- The coxa presents its bare SG90 spline through the cover opening; the femur rubs **directly on the cover's
  flat outer face `FACE_OUT` ≈ Y 35.1** (the RING insert is gone — COXA_SPEC R8). Femur hip = **Ø20 rub
  flange + horn interface** (embed or spline per the switch) on the inboard face.
- Assembly = translate the leg +Y so the flange seats on the cover face. No floating spline.
- **EXI caveat**: an OEM horn must clear the ~12×16 EXI top block poking through the cover opening — verify
  on a test print (SG90 fine).

## Lateral Y-layer stack (inboard → outboard), leg-local — FLIPPED (tibia inside)
**tibia Y[28.7,35.7] | (0.3 clr) | femur plate Y[36,43] + tab flats to Y45 | servo3 body Y[≈38,64], output
spline Y[34,36] on the knee axis (poking inboard through the plate slot)**. The tibia grips the spline just
inside the femur inner face (Y35.7 vs 36 = 0.3 clr, max engagement).
Leg width tibia-inner(28.7)→servo-outer(64) ≈ **35 mm**; the outboard face is servo-only (clean).
⚠ Trade-off: the inboard tibia costs frame clearance in EXTREME poses — see the decision log.

## Kinematic frame (v9 — current, verified against `legflat_v9.py`)
Sagittal x-z, +x = forward, +z = up, mm. Hip **H=(106,10)**, Knee **K=(106,−60)** (femur 70), toe (106,−140)
(tibia 80). servo3 axis **= the knee axis** (direct drive — no separate S, no linkage params).
Build stations are at nominal `HIPZ=10.0`; the export lift puts the shipped STLs on the measured axis.

## Manufacturing
- Every printable part = **single watertight/manifold STL** → `C:/ultrafish/robodog/stl/`, named
  `sm3sg90_v9_{femur,tibia}[_spline][_mir]`; **L/R mirrored** (chiral legs); fit Bambu 256 bed.
  Femur+tibia mirror about a **shared** bbox centre (`MIRC`) so the pair stays in one frame.
- PLA test. **FOOT**: plain **pointed blade toe** (the O7 ball foot was REMOVED per user 2026-07-28); foot0 z −144.1.
  A press-on TPU cap can still be added later for traction if the bare PLA toe slips.
- Frame: `framemin.py` → `sm3sg90_v9_frame.stl` (200 body + O16 splay-pin collars = 206 mm X, ~122 g). Corner blocks
  carry the coxa (R16 COXA/CLIP)/servo0/splay-dowel; bulkheads raised (BHH 28) for torsion. The leg mates the coxa only.
  **BUILD (splay dowel):** the O7.9 bore now carries a COARSE INTERNAL THREAD (P2.0 × 0.7 deep, ~13 mm) so a
  threaded/self-tapping O8 pin **screws in and self-retains** (user 2026-07-28); the O3 set-screw is a secondary
  lock. Ream/chase the printed thread before the first insert. **BELLY = ONE continuous chamfer (user 2026-07-28
  "match the head/rump chamfer on the belly, one larger chamfer"):** a single 45° bottom-outer chamfer runs the FULL
  length head→rump — wall at (BY/2, ZTOP=−11) down-and-in to (BY/2−DEEP=−12, zbot). It doubles as the **toe-in
  clearance**: a toed-in leg still clears at the hips — **~−30° toed-in gait = 0.0 mm³, LOCKED; −45° needs a slimmer
  femur housing.**
- **CLOSED ELECTRONICS TRAY (user 2026-07-28 "add webbing that closes the tray + redo the weight cutouts; hold the
  electronics safely; snap-on body eventually"; design-panel + adversarial-verify):** the tray (X±43.6 × Y±32.7 ×
  ~41 deep, OPEN TOP) is now a closed basket. (1) **Side walls** = a continuous **SKIN=1.2 mm inner skin** (the
  through-Warren truss is gone) with the outer 1.8 mm hollowed as a blind pocket braced by **4 external ribs/side**
  over z[tz0=−13, tz1=14.7]; solid **6 mm rim cap** above 14.7 for the snap body; keel solid below. (2) **Floor** =
  windows DELETED (solid **1.6 mm** shear panel; FLOORT 2.0→1.6 pinned the floor-top so only the belly rose 0.4 mm =
  more toe-in); zip-tie slots kept. (3) **KEEL WEB** = a **KWEB=1.4 mm** skin just inboard of the chamfer plane, X to
  ±(cbx0+0.5) so it ties floor→rail the full length + into the corner blocks (the chamfer had left a full-length gap);
  fused BEFORE the chamfer cut → trimmed flush, zero exterior/toe-in change. (4) **Battery corral** = 2 longitudinal
  floor ribs at Y±14 + a fore end-stop at X+30 (generic retention with the kept zip-ties). **Verified:** walls
  inner-skin 1.00, floor flat-zone 0.96 (zip-slots only, 0/768 holes), keel sealed incl. corners, upper-tray
  intrusion 0, toe-in/working/servo0 = 0, 1-solid watertight manifold, **122 g (3 g LIGHTER than the open version)**.
  Board-specific standoff bosses + a wall-to-wall diaphragm were **deferred** (board not chosen; diaphragm corner
  would float in the keel void). Top rim z=20.7 + outer face Y=±35.7 (top 6 mm) + corner-block tops left CLEAN =
  snap-body register (body designer: seat on the z=20.7 rim + Y=±35.7 face, anchor snaps at the 4 corner-block tops).
- **servo3 lead (no printed features on purpose):** the bone is a 7 mm flat plate — **zip-tie the lead
  around the plate** (2 ties up the thigh), cross the hip **near-axis over the flange top** with a small
  service loop, drop into the coxa's top wire slot. Same near-axis rule as v25/v26 wire routing.

## FreeCAD traps (do not relearn)
- `biggest()`/`max(Solids,…)` silently drops disjoint islands → guard with solid-count + volume asserts.
- Self-intersecting outline polygons → invalid faces → silent geometry drop → validate every fuse.
- Coplanar-touching solids don't fuse.
- `execute_code` returns a ~25k-token render → batch calls, read text only. When the MCP refuses connections
  the GUI is closed → build headless via `freecadcmd.exe` (Gui tails guarded with `App.GuiUp`).
- `slot(cx,z1,z2,r,…)` (racetrack helper) extends **±r past z1/z2** (disc caps) — pass z1−r/z2+r for a true
  extent (this nearly swallowed the mount pilots once).

## Verification (every build)
1. Knee fold sweep 0–70° (10° steps): tibia∩femur = 0 AND tibia∩servo-envelope(+0.5 clr) = 0.
2. Both parts valid single-solid; all STLs watertight/manifold/no-self-intersections (checked via `Mesh`).
3. L/R mirrors export to `/stl`; embed set keeps canonical names for `gen_urdf`.
4. Render before showing a pose — check fold direction (foot rear+up).

## Decision log (WHY only — never live values)
- 2026-07-27: **mount = body-through-slot + tab flats; knee connection made real** (user: "tibia still doesn't
  actually connect to the servo spline. femur servo body should fit thru a slot with offset flats for the tabs
  to sit against, no side wall like now"). Two root causes found by probing the SG90 mesh: (1) the old servo
  slot used **side rails**, not the panel-mount the user wanted → replaced with a body-through-slot + offset
  tab flats (a short knee tang carries the lower flat, which sits below the pivot). (2) "doesn't connect" was
  real for **embed** mode — the tibia captured the OEM cross-horn but that horn isn't in the STL, so tibia↔
  (missing horn)↔spline rendered as a gap; the knee now runs the **same `horn_iface` switch as the hip**, so
  embed = OEM-horn capture and spline = printed female gripping the O4.9 shaft DIRECTLY. The male spline is
  only ~2 mm (measured Y[34,36], flush to the case) → engagement maxes at ≈1.7 mm; the **M2 centre screw**,
  not the spline, carries pull-off (normal SG90-horn practice). It is a running-clearance coupling so
  `common()=0` is correct. Working-range & coxa gates still 0.00; full-envelope extreme trade-off unchanged.
- 2026-07-22: **knee FLIPPED — tibia to the inside** (user: "flipped so tibia is on the inside … servo slot
  shift outward so the spline is aligned for the tibia to be very close to the inside of the femur"). servo3
  output now points inboard, servo body sticks out outboard only (clean profile), tibia tucks against the
  femur inner face gripping the inboard-poking spline; femur mount reduced from a full cradle to a slide-in
  slot ("doesn't need full walls" — later hardened to a 2 mm closed box per the 2026-07-28 audit). ⚠ **Trade-off
  surfaced by the gate**: the leg (servo3 housing/tibia) hits the frame corner only when **positive pitch meets
  toed-in (negative) splay** (worst 708 mm³ at splay−25/pitch+45/knee70, + the pitch+90 extremes). With pitch≤0
  the leg swings AWAY from the frame, so the **whole default-gait envelope** (splay±25, pitch−58…−20, knee 41–70)
  is **clear (0.00)** and the dog stands+walks in PyBullet. Enforced by `kinematics.in_working_envelope` (coupled
  pitch×splay rule) + `poses.validate()` self-collision backstop. fold 0–70° 0, FEMUR∩servo3 5.1 (sliver).
- 2026-07-22: **"design doesn't actually work" pass** (user). Three fixes made it real: (1) frame servo0
  pockets get 2 mm walls all round bar the +Z insertion end (framemin); (2) the femur gets a servo cradle,
  not a flat-plate screw mount; (3) the tibia gets a spline receiver gripping the output directly. Probing
  for #3 exposed the root cause: **the servo3 output was 18.5 mm off the knee axis** (at −41.5, knee at −60),
  so nothing the tibia held could grip it — the leg was undriveable as drawn. Fixed by dropping the servo so
  its output boss lands on the knee (BOSS_OFF); user chose this over moving the knee, to keep femur 70/tibia
  80, accepting a ~10 mm servo overhang below the knee. All rebuilt: FEMUR∩servo3 0, fold 0-70° 0, assembly
  gates 0.
- 2026-07-21: **HPDZ lift restored in v9 export** — first v9 export shipped at nominal z and silently broke
  the v8-era STL contract (gen_urdf mates on the measured axis). The lift is a whole-chain translate, so the
  fold check (done unlifted, self-consistent) needed no re-run.
- 2026-07-21: **servo3 mount = M2 through the tabs into the plate** (tab holes happen to run along the plate
  normal — no bracket needed, the femur is the bracket). c-c 27.8 chosen to split the 27.5/28.0 clone spread
  rather than trust any one datasheet. Only after the mount was real did the body-footprint window go in.
- 2026-07-20: **v9 = direct-drive knee + 0.82× scale** (user: "ditch the tibia lever", frame → ~200 mm,
  femur 70/tibia 80 chosen via question). Reverses the v8 reduction the v7 audit demanded — accepted
  knowingly at the smaller scale; mitigation = MG90S at the knee + tucked gaits. Lightness beats ratio.
- 2026-07-20: **horn variants unified robot-wide** (user: leg parts "get the same embedded or printed spline
  recievers" as the coxa). 23T printed spline kept available despite the sub-nozzle tooth caveat — user's
  call, printability objection recorded.
- 2026-07-20: bones thinned **8 → 7 mm** (user). Linkage-facing faces held fixed so the mm came off open air;
  collision sweep stayed 0; mirror centre unmoved. ("No fork" was already true — v8 was single-shear.)
- 2026-07-11: (v8, superseded but kept for why-history) parallelogram → **reducing lever ≈2.5:1** to buy
  knee-torque margin; capped by SG90 travel. v9 traded that margin away for part count at smaller scale.
- 2026-07-11: servo3 kept **on the leg** (not body-mounted) — decoupling is automatic; fits the coxa build.
- 2026-07-19: hip datum moved onto the **measured** servo1 spline (z 10 → 10.3984), applied as a rigid lift
  at export, never by re-datuming `HIPZ` (that deforms the bone — profile stations are absolute z).
- 2026-07-19: coxa RING insert deleted (COXA_SPEC R8) → femur rubs the cover face directly, 1.5 mm inboard
  of the old rim. Any dy derived from the ring is wrong by 1.5 mm.
- 2026-07-11 (v7): user audit → single-blade + centered bores + Spot proportions; printed-spline-only horns
  rejected for driving torque (hence the embed default today).

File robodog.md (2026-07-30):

# ROBODOG — SG90 mini Spot

## Resume here (new session)
You're mid-project, not starting fresh — **this file is the restart doc.** Read the design bible below (visual target, the *verified* joint mechanism, rules, FreeCAD-MCP gotchas), then the **latest dated `### Update` at the very bottom** for the current state. Auto-memory `MEMORY.md` (loaded each session) carries the printable-parts deliverable + the joint-rotation-centre rule. Working dir: **`C:\ultrafish\robodog`** (a git repo; commit only when asked). ⚠️ The long history below (dog.py / leg4–7.py, SM3-loading, the outboard-femur redesign) is how we GOT here — the **current canonical files are the ones listed next, not `dog.py`**.

**Canonical scripts** (run via `exec(open(path).read())` in the FreeCAD MCP; there is no saved `.FCStd`). **⚠ Current phase = v9** (direct-drive, 200 mm — see the LAST `### Update`): the live builds are **`legflat_v9.py`** (leg, spec `LEG_SPEC.md`), **`coxablock.py`** (coxa, spec `COXA_SPEC.md`, unchanged for v9 per R15), **`framemin.py`** (200 mm minimal frame) and **`dog14.py`** (v9 assembly + clearance gates). All run headless via `freecadcmd.exe` when the GUI/MCP is down. dog13 below remains the v22-era reference/axes donor the v9 scripts exec for parts:
- **`dog13.py`** — the v22 canonical geometry (frame + 4 legs + 12 servos) + all gates + stance render. Gate log accumulates in `ref/iter/leg13_dog13.txt` (**read the TAIL** — latest run).
- **`part_body.py`** — ⚠ CURRENT cosmetic body: ONE-piece hollow **yellow** snap-on canopy → `stl/sm3sg90_body.stl`; single-feature head/rump, crown-spine rib, nub/post/peg/collar snaps. (The old 4-piece `bodyview.py` + the render/audit/pamphlet harnesses `assembly.py`/`frameview.py`/`legwork.py`/`poseview.py`/`pamphlet_render.py` were **removed in the 2026-07-30 cleanup** — git-recoverable / in a local attic.)
- **`horns.py`** — the 3-mode servo-horn receivers (arm/mesh/round); **arm** is canonical and now embeds the REAL horn mesh `servos/hornarm.stl`. **`dog14.py`** — v9 assembly doc (frame+pegs, coxae, real pins, legs, snap-on body) + clearance gates.

Operational must-knows before touching FreeCAD:
- `execute_code` returns a huge dark inline screenshot — write numeric reports/gates to a file and Read the saved **white-bg** PNGs (`ref/iter/*.png`) instead. `ref/iter/` is gitignored (regenerable).
- Every printable part must be a single solid (single **shell** too, for the hollow covers — a trapped void isn't printable); re-run the gates after any change. Mirror legs **L/R only**. Don't reinvent the verified joint mechanism.
- **Deliverable = 11 STLs → `stl/sm3sg90_*.stl`** for a Bambu **X1C** (256³): `v9_frame`, `body`, `coxa`+`_mir`, `coxa_cover`+`_mir`, `v9_femur`+`_mir`, `v9_tibia`+`_mir`, `pin` — all watertight/manifold, **first printable prototype 2026-07-30**. Chiral legs need L/R (`_mir`); pin prints ×4. Full table in `README.md`.
- **Colorway:** yellow body covers + yellow femur, black coxa/tibia/boot, grey servos (Spot-like yellow-body / black-leg).
- The user is a CAD / Octane-SDK expert: terse replies, ask a clarifying question rather than burn rebuilds, no trailing recaps.

## What we're building
A small, 3D-printable quadruped robot — **our own completely custom design**, driven by **12 SG90 micro-servos** (3 per leg). It takes visual/proportional cues from the Boston Dynamics Spot and the SM3 Spot-Micro, but **SM3 (and BD Spot) are REFERENCES ONLY — no external mesh or part is loaded or printed; every piece of geometry is ours.** Parametric, generated in **FreeCAD 1.1** through the FreeCAD MCP (`mcp__freecad__execute_code`). Working dir: `C:\ultrafish\robodog`.

The look matters as much as the mechanism. Judge the *look* of every render against the real-Spot photos in `ref/` (`n1_1` 3/4 view, `n2_1` side, `n3_1` leg closeup) and `BDspotdog.jpg` — but the design is **fully custom**: those images inform proportions and silhouette, not geometry.

## What "looks like Spot" means (the visual target)
- **Upper leg (thigh / femur):** a fat, rounded, smooth tapered link — the meaty part of the leg.
- **Lower leg (tibia / shin):** a long, slim, smooth blade. In *side* view it looks near-parallel; the taper is **lateral only** (wide-flat at the ankle, slim waist at the knee, fore-aft chord ~constant).
- **Foot:** a small **flat-soled pad / teardrop** (fore-aft : lateral ≈ 3:1). NOT a ball.
- **Body:** narrow and low — copy SM3's proportions (its body already looks right). A long, low beam, not a fat box.
- **Head:** a forward-facing sensor head — the single strongest "robot dog" cue.
- **Stance:** legs upright, feet under the body (no sawhorse splay), body floating high on the legs, tibia raked slightly forward-down.

## The one hard truth (read before designing)
An SG90 is **22.7 L × 12.1 W × 22.5 H mm**, output shaft on the top face 6 mm from the gear end. Each leg joint hinges about a **lateral (Y) axis**, so the servo's 22.5 mm shaft-axis dimension points **sideways**. Therefore:

> **Every direct-drive joint must bulge to ~26 mm wide laterally to swallow a servo.** The segments *between* joints stay thin and Spot-like. That is the honest look of Spot-with-SG90: **thin bones, bulged joint housings.**

Do **not** fatten the whole leg to hide the servo — that has repeatedly produced an ugly lumpy "banana," and the servo still pokes out at the joints anyway. If a genuinely slim shin is required, the only real fix is to **relocate the knee servo up into the thigh** with a push-rod / 4-bar linkage — but that breaks "direct-drive like SM3," so only consider it if the joint bulge looks wrong after a faithful attempt.

## Proportions (measured from real Spot; unit = trunk height TH)
- Trunk L:W:H ≈ 3.7 : 2.0 : 1.0 — but **use SM3's narrow body**, don't reinvent it.
- **Thigh : tibia ≈ 1 : 1.7** — the tibia is the *longest* bone. (Past builds inverted this and never read as Spot.)
- Hip modules = fat cylinders at the 4 corners, axis fore-aft.
- Foot ~0.36 TH ahead of the hip; belly floats ~1.78 TH off the ground; knee at ~0.60 of hip height.

## SG90 + hardware (locked)
- **Servo cutter** (build a parametric solid, never boolean against a servo mesh): body 22.7 × 12.1 × 22.5, tab span 32, tab thickness 2.4, output axis 6 mm from gear-end face centred on width, hub boss ø5.4 ~4 mm proud, wire exit at the motor end.
- **Coupling:** heat-set metal spline insert + M2 centre screw on each driven part (bore sized to the user's actual salvaged spline). No printed spline teeth.
- **Retention:** servo held by snap-fit + crush ribs.
- **Electronics:** Pi Pico / Pico W + PCA9685; 1S LiPo + 5 V boost.
- **Print:** ASA, enclosed printer, 0.4 mm nozzle (see **3D printing** below). Torque is marginal (~1.8 kg·cm) — keep it light; MG90S (~2.2 kg·cm) is a drop-in metal-gear upgrade, same footprint.

## 3D printing (ASA)
**Material — ASA.** Enclosed chamber, brim on every part, no draft on the door (ASA warps more than PLA — anchor layer 1). **A PLA test-fit is fine** for checking tolerances/assembly before committing ASA, but PLA is only a fit mule (won't take heat/load). Watch the shrink difference: **press/friction fits that are just-snug in PLA come out TIGHTER in ASA** — so tune the press fits (bearing cup, horn capture, coxa snap clips) on the PLA-loose side and expect ASA a hair tighter.

**General:** 0.4 mm nozzle, 0.2 mm layers, **3–4 perimeters** (at this scale the walls carry the load, not the infill), **gyroid infill** everywhere (isotropic — no weak axis, which matters at the joint housings). ~0.15 mm elephant-foot comp on parts with first-layer features (coxa spline face, femur wire groove).

**Per-part — min gyroid infill + notes** (infill is a floor; go higher if a print feels weak):
- **Coxa** (`sm3sg90_coxa.stl`) — **35 %**. **PRINT −X FACE DOWN** (spline-hole face on the bed). **PAUSE at 4.5 mm** (top of the print-in-place horn disk-chamber, one layer before the 2 mm roof closes) and **drop the round SG90 horn in** — splined shaft pointing down into the already-printed spline hole; resume and the roof layer captures it (no glue/fastener). Bearing cup crush-ribs are a **press-fit for the 688** (they carry a +X lead-in taper so it starts square). Snap-clip slots + servo pocket print support-free in this orientation. Servo drops in from +Y after printing; cover snaps on last.
- **Coxa cover / CLIP** (`sm3sg90_coxa_cover.stl`) — **15 %** (walls + the solid clips carry the load). Clips went through three PLA rounds: 1.2 mm flush → snapped at the root; 2.6 mm **proud** + proud root gusset → survived but stood off the coxa; now **FLUSH and chunky** — 3.5 mm beam, 14 wide, fully recessed (the block grew `CLIPGROW`/side to make room) with a flush lateral root gusset, beefier leg + r1.0 nub, 2-tab servo retention. Strain ~0.98 % so it still hand-snaps; flush means you release it by lifting the finger tip out of its channel, not by prying a proud lip. Print **outer (+Y / mouth) face DOWN**: that face is the femur bearing surface, so a clean bed finish matters — don't over-squish layer 1. Clips face up and, being thick + gusseted, survive support removal → only **light support under the nub/leg overhangs**.
- **Frame** — **40 %** (structural backbone / bearing-axle carrier). Print **deck-up**; the L/R shoulder girdle + gussets take the Ø8 splay pin; keep the M2 tab-screw pilots.
- **Femur** — **30 %**. Wire groove runs up the inboard print face → orient that face outward; brim + elephant-foot comp so the groove first layers stay clean. Servo2 (knee) pocket + 688/684 bearing seats.
- **Tibia / tibia_rear** — **25 %**. Slim blade — print **on its side (flat)** for strength along the length.
- **Body covers** (head / rump / trunk_lid / trunk_tub) — **12 %** (cosmetic; a couple perimeters give the cantilever latches their spring).
- **Splay pin** — **solid / 100 %** (6 walls). Tiny, must not shear.
- **Boot** — **TPU, separate plate.** 3 walls / ~20 % gyroid for grip + cushion; **print at the same scale as the foot-end** or it won't clip on.

## The joint mechanism (VERIFIED — reuse it, don't reinvent)
Built and gate-checked in `leg4.py` / `leg5.py`. Frame: **bone along X, hinge axis Y, profile in Z.**
- **Knee = rounded-knuckle direct drive.** The femur knee-end is a cylindrical cover pocket (radius RIN = R + CLR, R = 11) concentric with the Y hinge; the tibia's clevis top is a rounded cap that nests inside it. A circle rotating about its own centre sweeps itself → **the fold is collision-free by construction.** The tibia is a fork: +Y spline hub (heat-set), −Y idle peg into a femur boss, yoke joining the prongs.
- **Hip-pitch = a relocated copy of the knee** (also a Y axis): the coxa plays the femur role (holds the pitch servo), the femur proximal plays the tibia role (driven clevis).
- **Hip-roll = a −X barrel** on the coxa (cup + spline bore) mounting on the body's roll servo.
- **Travel:** knee ~110–125° (lie-down), hip-pitch ±45°, hip-roll ±45°.
- **Gates** (compute and write to a file *before* any render, so the numbers survive screenshot truncation): knee fold ≈ 0 at rest; hip-pitch interference low at neutral, ~140 at ±45°; **every part is a single solid**.

## How to make it smooth without lumps
Two viable strategies — prefer (B) if (A) keeps overshooting.

**(A) Analytic-ellipse lofts.** Build rings by scaling a `Part.Circle` to an ellipse (`transformGeometry`) — never loft faceted `makePolygon` rings (those give corncob stripes). Loft with `Part.makeLoft(wires, True, False)` (B-spline, ruled=False) and set `obj.ViewObject.Deviation = 0.02`.
- **Trap:** B-spline lofts *overshoot* when the section size ramps along the length — a 9→14 ramp ballooned to ~24 and broke the knee gate. **Keep each cross-section parameter constant or only very gently varying.** Constant section = exact width, no overshoot.
- **Gotcha (this session):** scaling a `Part.Circle` with `transformGeometry` scales about the WORLD origin, so a ring built at `(cx,0,cz)` drifts to centre `(cx, 0, cz·hz)` and the femur explodes in Z (saw 195 mm). Build the circle **at the origin**, scale, *then* `translate` it to its X station. See `dog.py:_ellA`.
- **Counter-intuitive but verified:** a *beefier* mid-bulge (ends frozen narrow, cosine bump to ~16 mm lat / ~14.5 vert) actually CLEARED the hip-pitch +45° gate the slim femur was failing (15943→0 mm³) — the B-spline reshapes the proximal end. So beef the thigh for the SM3 look; it won't break the gate as long as the joint ends stay frozen.

**(B) Primitive shells (more predictable).** Build the cosmetic links from rounded boxes / capsules / tapered prisms fused together. These never balloon, slice cleanly, and real Spot links are fairly geometric anyway. Often the more reliable path to a clean look.

Either way: **grow the cosmetic skin over the verified joint cores, then re-cut the servo pocket last** (so the pocket stays open). Don't redrape the joints. `makeFillet` throws `StdFail_NotDone` on lofted solids — bake roundness into the sections/primitives, don't fillet afterward.

## Rules (mistakes not to repeat)
- Don't ramp loft sections aggressively → overshoot/banana.
- Don't fatten the whole leg to enclose the servo → ugly; let the joint housings be the bulge.
- Keep thigh:tibia = 1:1.7 (tibia longer).
- Mirror legs **left/right only** — never front/back (that caused the sawhorse "footstool" splay).
- View every render against `ref/` yourself; numeric gates alone hid bad geometry before.

## Files (current — v9, after the 2026-07-30 cleanup)
The repo now holds ONLY the live v9 chain (all v3–v8 legs, old body/frame, and the render/pamphlet
harnesses were moved to a local attic / are in git history). See `README.md` for the build commands.
- **`dog13.py`** + modules **`dogcommon.py`**, **`part_femur.py`**, **`part_tibia.py`**, **`part_boot.py`**, **`part_shoulder.py`**, **`part_frame.py`**, **`part_dummies.py`** — base geometry, the MEASURED joint/splay axes, the scanned-servo cutter. Loaded via `dinc()`; **the source of truth for all axes.**
- **`framemin.py`** → `sm3sg90_v9_frame.stl` + `sm3sg90_pin.stl` (frame, snaps, alignment/central pegs, printed screw-in splay pin).
- **`part_body.py`** → `sm3sg90_body.stl` (one-piece snap-on canopy). Execs `dog14.py`.
- **`coxablock.py`** → `sm3sg90_coxa[_mir].stl` + `sm3sg90_coxa_cover[_mir].stl` (spec `COXA_SPEC.md`).
- **`legflat_v9.py`** → `sm3sg90_v9_{femur,tibia}[_mir].stl` (spec `LEG_SPEC.md`).
- **`horns.py`** — 3-mode horn receivers; arm canonical, embeds `servos/hornarm.stl`. **`dog14.py`** — v9 assembly + gates.
- **`control/`** — all-Python control/sim stack (`gen_urdf.py`, `kinematics.py`, `gait.py`, `poses.py`, `viz.py`, `explore.py`) + `robodog.urdf`. See `control/README.md`.
- **`stl/sm3sg90_*.stl`** — the 11 print-ready parts (canonical set).
- `ref/` — real-Spot reference images (`BDspotdog.jpg` etc.). `ref/iter/` (**gitignored**, regenerable) holds renders + gate logs. `servos/` = local reference scans (gitignored; **`servos/hornarm.stl` force-tracked** — build dependency).
- Auto-memory (loaded each session): `C:\Users\johnc\.claude\projects\C--ultrafish-robodog\memory\`.
- **Stale (old design, generator removed):** `pamphlet.html`, `robodog.pdf`, `robodog.3mf` — the 4-piece-body assembly manual; regenerate or drop before reuse.

## FreeCAD-via-MCP gotchas
- Each `execute_code` returns a ~25k-token base64 screenshot and has a ~90 s GUI timeout. **Print/write numeric reports to a file before any view op.** Minimize view ops; render to saved PNGs and read those instead of relying on the inline screenshot.
- In gate loops, reuse prebuilt solids (`rot(solid, -a)`), don't rebuild the loft per angle, or you hit the timeout.
- Session globals persist across calls: redefining a function overrides the stale one, but a *deleted* function lingers until the FreeCAD session restarts.

## Build plan
1. Reuse `leg5.py`'s verified joint cores — do not reinvent the mechanism.
2. Set the skeleton to thigh:tibia ≈ 1:1.7 at the chosen scale; recompute the hip frame.
3. Skin each segment with a **constant-section** smooth shell — analytic-ellipse loft (A) or primitive fuse (B) — thin between joints; fuse onto the cores; re-cut the servo pockets last.
4. Render with the skin translucent + servos solid-coloured; confirm each servo sits inside its housing; re-pass the gates numerically; compare to `ref/`.
5. Mirror L/R, place 4 legs on the narrow SM3 body + forward head. Export one leg's STL first and print it before committing the rest.

## Current state (session 2026-06-20) — `dog.py`
- **Working full assembly:** 4 legs (leg7 mechanism, **L/R mirror only**) + narrow low body + forward sensor head, posed standing. Reads as SM3 Spot-Micro against `ref/` / `BDspotdog.jpg`.
- **Gates all pass:** knee fold ≈0 at rest (`60≈138`, `110≈294`); hip-pitch clears at `−45≈140 / 0=0 / +45=0`; every printable part is a single solid.
- **Look polished:** smooth analytic-ellipse femur (no corncob), thigh beefed for mass; head has a dark sensor "face" panel; foot is a rounded boot pad.
- **STLs exported** → `stl/sm3sg90_{coxa,femur,tibia,body,head}.stl`, single solids, ~36 / 52 / 108 / 150 / 34 mm long (foot is fused into the tibia). One leg (coxa+femur+tibia) is printable **now** — print it to validate scale/fit before committing the rest (= step 5).
- **Biggest gap — body is still a solid block:** NO hip-roll servo pockets or electronics bay yet, so the legs can't physically mount to it. Next chunk: 4× servo-1 (hip-roll) pockets that mate the coxa barrels + a Pico/PCA9685/1S-LiPo bay with mounts and a snap lid.
- **Stance note:** the no-front/back-mirror rule still holds — but the *real* fix for the converging-feet "footstool" is to pose the feet **under the hips** (steep thigh + folded knee), not just to skip the F/B mirror. Pose tunables: `PITCH=66`, `KNEE_FOLD=45` at the top of `dog.py`.

### Update — internal-frame architecture (user direction)
User feedback: **longer femur**, **all knees forward** (rear legs same as front, NOT BD-Spot's rear-knee-back), and **legs on an internal frame that the body panels snap onto**.
- Done: `FEMUR_LEN = 54` (override + recompute `HX`/`HP`; femur loft freeze windows now scale with length → femur X-len ≈ 64, ratio ≈ 1:1.4). `FB_MIRROR = False` (all knees forward). Added `servo1()` (hip-roll SG90, coaxial with the coxa barrel, placed with the leg) so the 4 hip-roll servos show inside a translucent body. Gates still pass.
- **Geometry finding (drives the frame):** the coxa hip-roll barrel points −X. With no F/B mirror the **front** servos tuck inboard but the **rear** servos point out the back; the servo bodies also bulge ~8 mm past the side walls (= the shoulder bulge, which is fine — that's the SM3 "bulged joint housing"). So the body must (a) be wide enough at the shoulders, (b) extend rearward into a short **rump** to carry the rear hip-roll servos.
- **Next: internal frame + snap panels.** Build a structural chassis = floor plate + two side rails carrying the 4 hip-roll servo brackets (coaxial with the coxa barrels) + a central Pico/PCA9685/1S-LiPo bay, with snap rails on the top/side edges. The cosmetic trunk + head become separate **panels** that clip on (the current `body`/`head` solids become the panel shells). Frame is the printed structural part; panels are cosmetic.
- **Frame v1 built** (`dog.py`): per-leg `servo1_bracket()` (drop-in cradle, placed with the leg → lands coaxial with each coxa barrel) + a central chassis (floor plate, two side rails, top spine = panel mount, open-top electronics bay with a Pico/PCA9685/1S-LiPo envelope, spanning X[-103,38] back to the rear servos). parts=25, gates still pass. **Open issue it exposes:** all-knees-forward + the coxa's −X barrel ⇒ the rear hip-roll servos+cradles stick out the back and the shoulder servos bulge past the sides — resolve before panels (see decision).
- **Decision (rear hip-roll servos) — CHOSEN: (B) flip the rear coxa barrel to +X** so the rear servos tuck inboard (symmetric/compact). Build a `coxa_rear()` variant + rear `servo1`/bracket with the hip-roll barrel, bore, arm and servo on the **+X** side of HP, keeping the cradle/servo2/femur coupling and the femur/tibia unchanged (knee stays forward). Use it for the rear legs only in `place()`.
  - **Implementation gotcha (don't do a naive mirror):** a straight YZ-mirror of the barrel about HP lands it at ~X=HP.x+14, which is **inside the femur** (the femur runs HP→knee on the +X side). The +X barrel/servo must be **offset to clear the femur** — e.g. drop the hip-roll axis in Z and/or route the servo alongside/under the proximal femur — then **re-gate** (knee fold, hip-pitch ±45, single-solid) for the rear coxa. This is a real geometry edit, not a free mirror.
  - **DONE (`dog.py`):** added `coxa_rear()` (femur-coupling half identical to leg5 `coxa()`; hip-roll barrel/bore/arm on +X, dropped by `RC_DZ=-2`) + `servo1_rear()` (inboard, shaft −X into the +X bore) + a `leg_rear` parts list wired to the rear corners in the placement loop; `servo1_bracket(s=None)` now takes the servo so the rear bracket fits the rear servo. New gate line `hipR:`. **Result:** `hipR -45=7109 / +0=0 / +45=0  solids=1` — rear coxa is a single solid, servo body sits at leg-local X[−20,+2.5] (**tucked inboard**), collision-free at neutral and +45° (the displayed-pose side). **Cost:** loses −45° (up/back) pitch travel because the arm/barrel sit in the femur's −45° sweep; recover it by dropping `RC_DZ` further (lower roll axis) if full range is wanted. **Follow-ups:** the frame rump (floor/rails span back to X=−103 for the *old* rear-servo position) is now over-long and can be shortened; then skin the snap-on panels.
- **Frame v2 + body stretch (`dog.py`):** frame extent now **relative to the hips** (`hxc = BL/2 − HIP_INSET`; `fx0=−(hxc+22)`, `fx1=hxc+8`) so it auto-follows — bottom plate (legs/servos) + top deck (panel snap-mount + electronics shelf above the central servos), no rump. **Body stretched `BL 150→190`** (L:W ≈ 3.8:1, SM3 trunk proportions); both servo clusters and the bay now sit central as the hips spread. Gates unchanged.
- **Open (stance):** with all-knees-forward + `PITCH=66`, both front and rear feet are pulled forward, so the legs cluster in the middle third of the long body and the rear overhangs past the rear feet. To spread the feet toward the corners (fuller Spot stance) either reduce `HIP_INSET` (hips toward the ends) and/or ease `PITCH`; rear-leg back-pitch is limited by the `coxa_rear` −45° collision.

### Update — KNEE_BACK (knees toward tail, normal root)
SM3 fact (from the `Nova-SM3/STL Files` + `novasm3.png`): leg links are **L/R only** (`Left/Right Coax/Femur/Tibia`) — front & rear legs are the *same* parts, all four oriented identically; the front/rear difference lives in the **shoulders** (`FrontShoulder*` vs `RearShoulder*`). User wants **all knees pointing toward the TAIL**, head forward, with a normal root transform (do NOT move the head to −X).
- **Done (`dog.py`):** `KNEE_BACK=True`. In `place()`, `xmir = KNEE_BACK ^ (sx<0 and FB_MIRROR)` flips **each leg in X** (mirror about O, `hx=-HP.x`), so knees face the tail while body/head stay at +X (root unchanged). In the placement loop the front/rear coxa roles **swap** when `KNEE_BACK` (`front→coxa_rear`, `rear→coxa`) so the hip-roll servos still tuck inboard after the flip. Mechanism untouched ⇒ gates identical (`knee 0=0`, `hip ±45`, `hipR` same, all solids=1).
- **Stance now:** knees bend rearward, feet sit under / slightly behind the hips (a touch central). Spread toward the corners via `PITCH` / `HIP_INSET` if a wider Spot stance is wanted.

### Update — session 2026-06-26 (real SM3 foot-end, TPU boot, centred hip-pitch; → Bambu A1)
- **Tibia foot-end is now the REAL SM3 toe.** `dog.py` loads `SM3_Frame_LeftTibia` (S=0.66), isolates its foot-end (the paw/toe with the boot-snap hole), **rolls it 90° about the shin long axis** (its profile lives in X-Y with the hole along Z, so it must roll to sit sagittal with the hole lateral), pitches it forward `FOOT_PITCH≈17°` about the lateral axis at the ankle (rounded sole ~tangent to ground), and **morphs the round shin's last 30 % into the foot-end's join ellipse** so it's one seamless solid (`tibiaF` / `tibia_shank_round`).
- **TPU boot is a tracked deliverable.** `sm3_boot()` loads `SM3_Foot.stl` at the **same S=0.66** so the snap fit is preserved (24.4×13.2×13.2). Exported as `sm3sg90_boot.stl`, **printed separately in flexible TPU**; every other part is rigid. If the foot-end scale ever changes, keep the boot on the same scale or it won't clip on.
- **Deliverable target = Bambu Lab A1** (256³ build volume). Six print-ready STLs now: `stl/sm3sg90_{coxa,femur,tibia,boot,body,head}.stl` — all fit one plate (largest = body 190×50×33). Full dog = 4× each leg part + 1 body + 1 head. (Stale `sm3sg90_foot.stl` from the pre-boot naming was removed.)
- **Hip-pitch axis re-centred on the femur (structural fix).** It sat ~11 mm above the thigh centre because `HZ` was `kneeZ(FENV)` in the *unshifted* envelope frame while the round femur is built `FDZ`-shifted. Fixed in `dog.py`: `HX=-FEMUR_LEN`, `HZ`=the round femur's proximal centreline ⇒ axis on the top-centre (dX=dZ=0), femur shape unchanged, stance 133→131 mm. **Rule (now in auto-memory):** every joint's servo axis must pass through the geometric centre of the part it drives — watch for this same frame-mismatch on the knee / ankle / hip-roll.
- **Joint-centre audit DONE — rule holds everywhere except the rear hip-roll (by design); no new frame-mismatch bugs.** Measured each servo axis vs the driven part's centroid at the joint station (`ref/iter/joint_audit.txt`): hip-pitch `dZ≈+0.2` ✓ (the fix holds), knee `dZ≈−0.2` at the knee (coupling exact by construction; the `+3.7` at mid-shank is the intentional `−3·sin` shin bow, not a joint error) ✓, hip-roll **front** `dZ=0.000` ✓ — **the `HZ` move did NOT break hip-roll because `coxa` and `servo1` both read `HZ`, so they tracked together** — ankle N/A (no servo, foot fused rigid). Only the **rear hip-roll** is off-centre: `dZ≈−2.1 = RC_DZ`, the deliberate drop to clear the knee-forward femur (eccentric on its roll bearing, costs −45° pitch). Inherent to tucking the rear servo inboard: un-dropping re-collides the barrel with the femur; dropping the whole `coxa_rear` to match would break the hip-pitch coupling — so leave it unless full rear pitch range is wanted (tune `RC_DZ` ↔ eccentricity ↔ femur clearance).

### Update — body scaling + joint spread to SM3 / real-dog proportions (Spot-proportioned)
User direction: match body **W & L** and the **leg spread** to SM3 + general real robot-dog designs; THEN do joint clearance with **all 12 SG90 meshes** placed (the parametric servo boxes lack the 32 mm tab span, so the real mesh is needed to test true clearance).
- **Measured references** (`ref/iter/proportions.txt`, all ×0.66 = build scale): SM3 trunk (`SM3_Frame_ChassisTrunk`) 84×73×31 → L:W **1.15:1** (central box, short/wide; the full torso is longer once the front/rear shoulder modules are added); SM3 femur:tibia 91:85; real-Spot posed footprint L:W:H ~2:1.4:1. **Real SG90 mesh = 32×30×12.5 (tab span 32) at `C:/ultrafish/3dprint/SG90-Servo.stl`** — servos are NOT scaled, place at **s=1.0**; MG90S upgrade mesh = `C:/ultrafish/3dprint/MG90S_Servo.stl`. The old body 190×50 (L:W **3.8:1**) was far too long-and-thin vs both SM3 and real dogs.
- **DONE (`dog.py`) — Spot-proportioned 2.3:1 (user choice).** `BL 190→168`, `BW 50→72` (L:W **2.33:1**); `HIP_OUT 2→6` (track 54→**84**); `HIP_INSET 28→22` (wheelbase 134→**124**, feet toward the corners). Body **height 33 unchanged** (already = SM3 ×0.66). Head width fraction **`0.60→0.45·BW`** so the widened body keeps a length-dominant snout (34 ≥ 32.4, not a wide muzzle). Frame floor half-width `20→BW/2−5` (tracks BW, stays inside the walls). **Bones/mechanism untouched ⇒ knee/hip/hipR gates identical; stance 131 mm; all parts single solids.** New gate line `PROPORTION: body 168x72x33 L:W=2.33:1 track=84 wheelbase=124`. Reads as a proper Spot/robot-dog torso now (top/iso renders); hip-roll servos bulge ~6 mm past the side walls = the SM3 shoulder bulge (honest SG90 housing).
- **Tweak (user) — longer body + rump.** `BL 168→185` (~10% longer); new **`RUMP=14`** extends the body **rear (−X) only** ⇒ shell **199×72×33, L:W 2.76:1**, wheelbase 124→**141**, **rear/front overhang 36/22** (the rump). Note: the symmetric body's overhang past each hip is fixed at `HIP_INSET`, so a real rump *requires* the explicit rear extension (`body = roundbox(BL+RUMP, …, v(-(BL/2+RUMP), …))`; head stays at the +BL/2 front face). Gates unchanged; reads as a longer Spot with fuller hindquarters.
- **Tweak (user) — front/rear hip-roll servos at EQUAL elevation.** User spotted the front hip-roll servo sitting 2 mm below the rear: with `KNEE_BACK`, front legs use `coxa_rear` (barrel dropped `RC_DZ=−2` to "clear the femur") and rear legs use `coxa` (un-dropped) ⇒ the two roll **axes** were at different Z, so the joint didn't roll equally front-to-back. **Fix: `RC_DZ −2 → 0`.** Measured `coxa_rear` vs femur = **20 mm³ either way** (single solid) — the +X barrel sits on the femur centreline `HZ` with **no new collision** (the doc's old "barrel hits the femur" warning was stale for the smooth femur). Both front & rear roll axes now at `HZ=5.233`, **on-centre and equal**. ⟶ **This supersedes the joint-centre audit's "rear hip-roll off by design" finding — it's on-centre now too; all joints on-centre.** Gates unchanged (`hipR +0`≈6.8k is the peg-in-boss coupling, single solid). Residual (minor, doesn't show in the +66° posed render): the +X-barrel side still loses some −45° hip-pitch travel because the barrel sits near the femur — inherent to tucking that servo inboard.
- **Lie-down (user: "feet down, legs folded till belly touches the ground") — GEOMETRIC LIMIT FOUND + feet-down crouch.**
  - **Hard finding: feet-down + belly-flat + folded is geometrically impossible with this leg.** Leg = femur 68 + tibia 82 = **150 mm**. Belly-on-ground ⇒ hip only ~18 mm up ⇒ the leg must fold so hip & foot are 18 mm apart vertically = a **~175° knee bend**, where `femur∩shin ≈ 7723 mm³` (vs ~150 bearing) — un-foldable self-collision. The lowest **clean feet-down crouch** (knee ~90–100°, no collision) leaves the **belly ~60 mm up** (half standing height); below that the knee collides. A belly-flat pose forces feet **up**, knees **up**, or legs splayed **out** ~110 mm. The long SM3 shin (1:1.2 femur:tibia) simply won't tuck flat under an 18 mm-high belly. *(IK tables: `ref/iter/liedown_ik.txt`, `liedown_ik2.txt`.)*
  - **Sign trap that bit me:** standing knee fold is `tibiaF(+45)` = **feet-down**. My first lie-down render used `tibiaF(−115)` (the **opposite**, feet-UP) → dog on its back, legs in the air. The fix is `tibiaF(+)` (steep hip pitch so the knee drops near the ground, shin folds back, foot planted).
  - **DELIVERED: feet-down crouch** (`crouch.py`, `ref/iter/crouch_side.png`/`crouch_iso.png`) — PITCH≈78, knee≈100° (feet-down), feet planted, body sunk onto the folded legs, belly ~64 mm up. Reads as a natural folded-leg rest. *Pose only; does not change the printed bones.*
  - **Cleanup:** reverted the two edits made for the abandoned belly-on-ground attempt — the 6 mm **frame drop** (`floor` back to thickness 5 / base `bz0−1`) and the **top-relief widening** (leg4 `relief` Y back to 11). Standing geometry restored; gates unchanged.
  - ~~TODO femur-front relief~~ — **superseded by the canted-knee flat fold (below)**, which clears by swinging the shin sideways instead of scooping the femur front.
- **Shoulders to deck + canted-knee FLAT FOLD (user directive: "shoulders to top of frame; folded = femurs back ~level, tibias as level as possible; redesign the joint with an offset/angle for close folding").**
  - **(1) Shoulders to top (done, in `dog.py`).** `HIP_DZ −4 → 11.0` (hips at deck level); `bz0 = HIP_DZ − BH + 7` (body hangs *below* the high hip ⇒ max belly freeboard so folded legs tuck up clear of the belly). Standing stance **115.7 mm**, gates/single-solids unchanged. Side-effect (flagged): standing belly sits *lower* (131→116) because the body hangs under the raised hip — correct for the fold; re-tune standing `PITCH` if the clearance is wanted back.
  - **(2) Canted knee — the mechanism.** A pure in-plane flat fold collides (`femur∩shin ≈ 7700`). Fix = **tilt the knee hinge axis off pure-lateral (Y) toward +X by `α≈30°`**, with the cant's **neutral (zero lateral offset) set AT the standing knee angle (+45°)** — *standing-referenced*. Consequences (verified, `ref/iter/cant_std.txt`): **standing is the un-canted geometry ⇒ foot stays dead-centered, no track offset** (user hard constraint "foot shouldn't be offset"); the shin swings **+Y only as it folds past standing**, clearing the femur shaft (`femur∩SHAFT`: 6900→~150 mm³ at α30/FOLD160, excluding the knuckle bearing). The shin therefore **splays laterally** when folded (~one bone-width+ out) — this is unavoidable (the shin must go *somewhere* that isn't the femur); **user accepted the splay.** "Not fully flat is OK" ⇒ FOLD≈160°, not 180.
  - **Pose delivered (kinematics):** `foldflat.py` (synced) — `ALPHA=30, FOLD=160, PIT=0` (femur ~level), standing-referenced canted fold `rot(tibiaF(45), FOLD−45, O, â)`, `â=(sinα,cosα,0)`. Feet-down, legs folded, **belly/frame 8.7 mm above ground**. Renders `ref/iter/foldflat_side.png`/`foldflat_iso.png`. Verified feet-DOWN / belly-low (not the earlier upside-down trap).
  - **Bake-in DONE — `KNEE_CANT` param (leg4.py, default 0.0).** `_cant(s)=rot(s,−KNEE_CANT,O,Z)` tilts the Y bore→â; applied to the femur knee-servo pocket (`cradle/cav`), idle boss (`pegb`), knuckle cover + reliefs (leg4 `femur()`), and the tibia clevis (`rootcap/hub/peg/yoke` in dog.py `tibiaF`) — shank/foot stay in-plane = the **doglegged clevis**. `tibiaF`'s fold is standing-referenced: `rot(rot(tib, KSTAND, O, Y), fold−KSTAND, O, _caxis())` — fold to the standing knee angle **about Y first** (so standing is the original in-plane pose), THEN swing the extra about the canted axis. ⚠️ The naïve `rot(tib, fold−KSTAND, â)` is WRONG: it makes `fold==KSTAND` the *extended* bone, changing the standing knee angle (caught because stance dropped 115.7→113.3 and the tibia STL grew to 93.9×38.9 — heed [[verify-posed-renders]]).
  - **SHIPPED — default `KNEE_CANT=30.0`** (set 0 to revert to the original Y-hinge model). `tib0`/STL export uses `tibiaF(KSTAND)` = the in-plane folded-45 standing bone (clean print orientation). **Verified (`ref/iter/cant_fix.txt` + build log):** all 6 parts **single solid** (femur 84.7×36.2×31.1, tibia 73.3×38.9×71.4); **stance 115.7 mm = unchanged from the un-canted model** — standing foot/shank are identical (overlap-check: shank+foot shared, the ~1.7k-mm³ delta is only the canted clevis). Folded shin clears per `cant_std.txt` (shaft∩femur ~150 at α30/FOLD160). `foldflat.py` can now drop its manual cant math and just set `KNEE_CANT=30` + `tibP=rot(tibiaF(160),PIT,HP,Y)`.

### Update — session 2026-07-02 (SM3 removed from geometry → design is now fully CUSTOM; coplanar-knee revert; hip-roll servo flip)
**This supersedes the "SM3-style Spot-Micro / must read as SM3" framing at the top — the design is our own; SM3 is a reference only.**
- **SM3 removed from the printed geometry.** SM3 meshes were being *loaded as real geometry* — `load("SM3_Frame_LeftFemur/Tibia")` for the femur/tibia envelopes (`FENV`/`TENV`) + foot end, `load("SM3_Foot")` for the boot. Now:
  - `FENV`/`TENV` in `leg4.py` are **hardcoded constants** (the SM3 reference proportions captured as plain numbers) — no mesh loads. Every derived value is byte-identical: `HZ=5.233`, `RPROX=9.194`, `FDX/FDZ/TDX/TDZ` unchanged, **femur vol=29713 (exact match)** — femur/tibia dimensions did not move.
  - Foot end + boot are now **custom primitive geometry** (`_make_foot_end`/`foot_end()` = rounded paw + lateral boot-snap hole; `boot()` = hollow TPU cap). Verified single solids, clean tibia fuse (`ref/iter/nosm3_leg.png`). Nothing external loads during a build. (The old leg2/3/6 iterations that also loaded SM3 are now deleted; a residual `load("SM3_Foot")` survives only in leg4/leg5's *overridden, never-run* tibia functions — in dog's namespace but off its build path, harmless.)
- **Reverted the canted knee → coplanar knee** (`KNEE_CANT=0`). Flattened the dead cant machinery (`_cant()` no-ops + branches), **cached the tibia base solid** (built once, rotated per fold — big build-time win), removed no-op `FB_MIRROR`/`RC_DZ`. Straight round **smooth femur kept** (the shape we want).
- **New fold-flat approach:** flip the **hip-roll servo (`servo1`) vertically** so its body sits *above* the roll axis, opening space below for the folding femur — **verified 0 mm³ femur clash at every fold angle**; `servo1_bracket` cradle flipped to match (mount foot stays on the deck). (The servo1 flip is a real clearance win and stays.) **Subsumed as the *primary* fold enabler by the servo2-vertical rework — see "Next" at the very bottom.**
- Baseline before this session: 34 parts, 0 collisions, stance 115.7 mm, femur:tibia 1:1.20 (`ref/iter/dog_gates.txt`). Deliverable unchanged: 6 print-ready STLs for a **Bambu Lab A1**.
- **Codebase cleanup (verified by a 45-agent read-only analysis + a one-leg build; full-dog build still pending).** Deleted the dead old-iteration files (`leg2/3/6.py`, `spot_leg.py`, `spot_servo_leg.py`, `knee_concept.py`, `build.py`) and the stale one-off pose scripts (`crouch.py`, `foldflat.py`) from BOTH mirrors — all git-recoverable, none in dog's exec path. Removed dead `_ellA()` from dog.py and **hoisted the femur sweep-proxy** (built once, not twice). Kept `leg_v1_cantilever_KEEP.py` (protected) and `belly_pan()` (dead but a real intended part — pending user call). NOTE: the active chain `leg4/5/7.py` still carries its standalone test-harness `main()`s and the reverted **canted-knee machinery** (`_cant`/`_caxis`/`KNEE_CANT=30`/`KSTAND`); those are dead for the build but tangled with the `rfind("\\nmainN()")` exec-slicing AND `_cant` still runs as a no-op via the `_femur4`→`_femur5` capture chain — do NOT bulk-delete (the auto-verifiers wrongly flagged them). A proper flatten of leg4/5/7 into dog.py is a separate, hand-verified pass.

### ~~Next — servo2 VERTICAL, spline on the BOTTOM~~ (SUPERSEDED same day by the FULL LEG REDESIGN below — do not build this)
**User call:** reorient the hip-pitch servo (`servo2`) to **vertical with its output spline pointing DOWN**. This is judged the *only* way to fold the femur **and** tibia up close to flat; with it, the femur should fold **nearly flat both forward and backward**. The **femur proximal pivot-fork length** must be sized to permit that swing. Target: a **collision-free** frame + leg across the full fold range, front and rear.
- Intent to verify: a bottom-spline vertical servo2 tucks the hip-pitch drive under/inside the hip so the servo body no longer blocks the femur root at extreme fold, freeing the thigh to lie back (or forward) near-parallel to the belly.
- Geometry to pin when modeling: servo2's envelope in the new vertical/spline-down pose vs. the coxa cradle, the frame deck, and the hip-roll (`servo1`) housing; the pivot-fork length/offset that clears the frame at max fold in BOTH directions; keep the knee pivot centered on the femur's distal end; then re-run the full gates (hip-pitch sweep, knee fold, single-solid) front and rear until collision-free.
- Status: **design direction only — not yet modeled.** Next session: deep-think the servo2 placement + fork geometry, then build and drive the gates to collision-free.
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

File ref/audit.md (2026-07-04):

# ROBODOG design audit — 2026-07-01

All volumes mm³, measured in FreeCAD on the placed assembly (26 parts) + leg-local sweeps.
Raw data: `3dprint/sm3-sg90/ref/iter/audit_static.txt`, `audit_sweep.txt`, `audit_fix1.txt`, `audit_fix2.txt`.

## Verdict summary (numeric audit)

| # | Severity | Finding | Status |
|---|---|---|---|
| 1 | CRITICAL | Front-hip `coxa_rear` interpenetrates the femur at every pitch (6841@0° → 1983@66°); rear coxa 1983@66 stance too. | **FIXED** — `_sweep_clear()` carves the femur's swept envelope (scaled 1.05 about HP, journal masked) out of both coxa types. Post-fix: rear 0–48 over walking range, front 12–271 over 41–91°. Foldflat 0° stays impossible for front hips (femur coaxial with barrel) — documented. |
| 2 | CRITICAL | Front leg forward-pitch blocked by own bracket+servo beyond ~stance+20–28°. | Inherent to the inboard tuck; documented as a firmware limit (fwd pitch ≤ stance+20°). |
| 3 | CRITICAL | Cover "snaps" do not lock (upper friction-only, monotone decay 446→379; lower wedges 238→520). Nub y26..27.6 never meets flange y28..33.8 (0.4mm air gap), no Z undercut. | OPEN → covers redesign. |
| 4 | CRITICAL | Frame ends poke into the covers' rounded front wall (cover_up^frame 446 @x[88,92.4]; cover_lo^frame 238). | OPEN → covers redesign. |
| 5 | CRITICAL | Head unmounted + collides (frame 1542 / cover_up 971 / cover_lo 944; root x86.5 vs cover end x92.5). | OPEN → head socket + forward shift. |
| 6 | MAJOR | Bracket mount foot pokes upper-cover ceiling ×4 (235; deck→ceiling gap 1.8mm). | OPEN → ceiling relief or deck pocket. |
| 7 | MAJOR | On-deck electronics impossible (1.8mm headroom). | **FIXED** — elec dummy moved into the cavity (bz0+10, on standoffs). |
| 8 | MAJOR | Adduction roll ≥25–30° drives femur into frame (336@-25°, 1942@-40°). Walking ±20° clean. | Documented as firmware roll limit ±20°. |
| 9 | minor | Femur grazes lower-cover hip lip (290×4); knee 110° foot-up fold = 866. | Lip → strip redesign; fold direction see #27 below. |
| 10 | minor | 8 unused cover-peg holes; stale rails comment. | Comment fixed; peg holes → covers redesign. |

## Second-pass findings (40-finding multi-lens workflow sweep, adversarially verified)

Fixed this session:

- **Bracket end-wall + shell overlap the coxa roll barrel 503/215** (the numeric audit's "constant under roll → bearing" call was WRONG — constant because both parts are rotationally symmetric there; two printed parts still can't share space). Front-variant end wall also sat across the horn (shaft relief cut at `bb.XMax` = tail for `servo1_rear`). **FIXED** — horn end auto-detected (thin end-slab volume), r8.6 × 12 bore cleared through it. Verified brkt^coxa = 0 on all 4 corners, roll sweep ±40° all 0, brackets single solids.
- **Outer bracket screw hole 0.5mm off the frame pilot** (holes were `bb.XMin+8 / bb.XMax-8` where bb includes the 8mm horn → 14.5mm spacing vs 15mm pilots). **FIXED** — holes at `bb.XMin+8 / +23`. Screw probes: x25 clean; x40 probe still meets 0.8mm³ of reveal-post material *below* the pilot = self-tap bite, fine.
- **Knee gate swept the wrong direction** (foot-up folds {45,-15,-65}, while crouch/foldflat fold feet-DOWN past standing). **FIXED** — added `kneeD` gate at +55/+100/+115: 689/1137/1314. Crouch fold ~100 needs a femur-front relief before deep crouch is physically clean (known, crouch.py header).
- **Export chirality undocumented** (as-exported = RIGHT-side legs; LEFT legs are true mirrors; canted tibia+foot are chiral). **FIXED** — documented at the export block: print one set as-is + one set slicer-mirrored.
- **crouch.py placed the body 15.5mm too high** (`bz0 = HIP_DZ-BH/2+6` vs dog.py's `HIP_DZ-BH+7`), invalidating its belly-height readout. **FIXED**.
- Missing `sm3sg90_coxa_front` STL (front legs use `coxa_rear()` but it was never exported; slicer-mirroring cannot produce it from the rear coxa). **FIXED** earlier this session.

Mechanism-level fixes (user-approved "fix all those", 2026-07-01 second pass):

- **No axial retention on the hip-roll joint** — **FIXED**: M2 horn-screw channel (r1.1 through + r3.0 counterbore/driver channel) cut through both coxa barrel backs, 2mm head shoulder behind the spline bore. Verified: screw path clear both types; rear shoulder ring full (31.7mm³); FRONT shoulder only ~30% survives the femur sweep-clearance — use a washer under the front horn-screw head. Assembly order: screw the coxa onto the horn BEFORE the femur enters the cradle (the knuckle blocks the driver channel after).
- **SG90 dummy wrong (centered shaft, no tabs)** — **FIXED for the hip-roll pair**: `_sg90_roll()` true geometry (22.8×12.2×22.5 body, shaft 5.5mm off length-center, tabs w/ screw holes, lead stub). Bracket rebuilt: open-top drop-in pocket, bottom-tab slot through the floor + M2 boss (tab screw = servo can't lift out, fixes "no servo retention"), r8.6 roll-barrel bore, mount foot keyed to the output face (screws land exactly on the frame pilots — verified with r0.95 probes, all corners). brkt^coxa=brkt^servo=coxa^servo=0 everywhere. NOTE: servo2/knee servo already had the offset shaft; they got tabs/lead/spline-r2.4 via `_sg90_pitch()`.
- **8 of 12 servos absent** — **FIXED (in verification)**: `servo2()`/`servoK()` (true SG90, knee one canted per KNEE_CANT) placed in all 4 legs → 34 parts. Placement measurement revealed the deeper truth: the rotating knuckle caps sweep THROUGH the servo bodies (rootcap vs knee servo 760–2171mm³ at every fold; femur knuckle vs servo2 1670–2009 at every pitch) and the coxa bridge ARM was fused straight through servo2's body (1722/387). Fixes: swept-envelope carves (16-step fold sweep out of the tibia rootcap; 12-step pitch sweep + static pocket/tab-slot envelope out of the femur; servo2 pocket cut out of both coxae). The joint bearing is the +Y spline hub + −Y idle peg (as in the real SM3); the caps survive as partial nesting arcs.
- **Knee clevis idle arm vs femur boss (252 solid clash)** — **FIXED (in verification)**: pegarm+peg swing sector (13-step) carved out of the femur idle boss; bore keeps the r3 peg. Idle pegs/arms also shortened 1mm (y −19..−14) on both femur and tibia: the real SG90 body reaches y −13.5 (was 0.5mm interference).
- **Clevis hub bores** — **FIXED**: modeled spline r2.7→r2.4; hub bores now r2.5×4.7 spline pocket + r1.2 through = M2 clamp-screw shoulder (head no longer falls through), both knee (tibia) and hip-pitch (femur) hubs.
- **Electronics serviceability** — **FIXED (in verification)**: r2.0 driver holes through the deck above all 4 standoffs; LiPo belly hatch (60×24) in the floor under the pocket + 4 strap slots — battery swaps through the open belly.
- **TPU boot chirality** — **FIXED**: second mirrored export `sm3sg90_boot_L` (as-exported tibia/boot = RIGHT feet).
- **Foldflat limits** — documented in foldflat.py header: PIT=0 unreachable (front coxa + intact central cover band; real floor ≈26–31°); canted fold splays feet ~62mm/side.

## What's GOOD (verified)

- **Mirroring is exact**: every leg-pair volume identical across all 4 legs. One printed leg + slicer-mirror is sound (see chirality note in dog.py exports).
- **All 26 parts single solids**; all 10 STLs export 1-solid.
- Knee pivot 252 constant (but see clevis/boss note above); servo seats servo^coxa=servo^brkt=0; bracket↔coxa now a true clearance bearing (0 through ±40° roll).
- Rear-type coxa post-fix: 0–48 across the walking window; front-type 12–271 over 41–91°.
- Bracket foot ↔ deck M2 screws align exactly (15mm spacing = pilots).
- Frame + leg fit the A1 bed; boot pairs with the SM3 foot by construction.

## Covers / side-strip / head redesign (audit #3/#4/#5/#6/#9/#10 — implemented 2026-07-01)

- **Upper clamshell** (snap-on): shell z≥4 (side strip widened), length +4 so the front wall CLEARS the frame end (was embedded, #4). Full-height hip windows unchanged. 4 ceiling windows over the bracket mount feet (#6 poke fixed + M2 driver access from above). Front-wall opening for the head plug.
- **Snap latch** (#3 fixed): 3 catch ARMS per side on the frame (deck edge → y34.4, z10..13) pierce matching WINDOWS in the cover side wall; the wall panel flexes ~0.8mm on push-down, then the arm is pinned in the window = positive vertical lock. Old non-engaging nubs/flanges deleted.
- **Lower cover DELETED** → **screwed belly pan**: the femur crosses the wall band y[33.8,36] from z0 to ~−19 at every working pitch (290mm³ lip graze, #9; roll grinds deeper — hip-roll had zero clean travel), so no lower side wall can exist in the hip windows and the "one-solid lower ring" is geometrically dead. Flat pan (164×48×1.6) under the floor, 4× M2 into repurposed floor pilots (#10: deck-side dead holes deleted), hatch window matching the frame's LiPo hatch.
- **Head mounted** (#5): root moved to x96.7 (0.2 clear of the cover front), under-deck plug + 2× M2 down through new deck pilots. Face panel follows.
- **Side strip**: one bold open band from the shell's z4 edge down to the pan — dark frame rails/posts read through it ("like SM3 but even better" = wider, continuous, frames the legs).

## Final verification (34-part placed assembly + covers, 2026-07-01)

Contact matrix residuals — everything else is 0: tibia^servoK 135×4 (rootcap-arc sliver at standing; was 760+),
femur^tibia 38×4 (knee pivot graze; was 252), femur^servo2 10×4 (sweep tolerance), cover_up^frame 9 (catch arms
seated in their windows), head^face 54 (cosmetic, intended). Latch lift test 1→16 mm³ ramp = arms pinned in the
windows (positive lock); slide-on flex load 15–29 mm³. All 11 STLs single solids.

Gates: knee 0/60/110 = 38/48/199 · kneeD +55/+100/+115 = 79/661/881 · hip −45/0/+45 = 21/4/0 ·
hipR −45/0/+45 = 1832/4/27 (−45 is outside the front-hip demand; walking 41–91 clean) ·
svc2 = 8–10 at all pitches, pockets 0 · svcK −110/0/+55/+115 = 156/135/222/945, cradle 0.
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

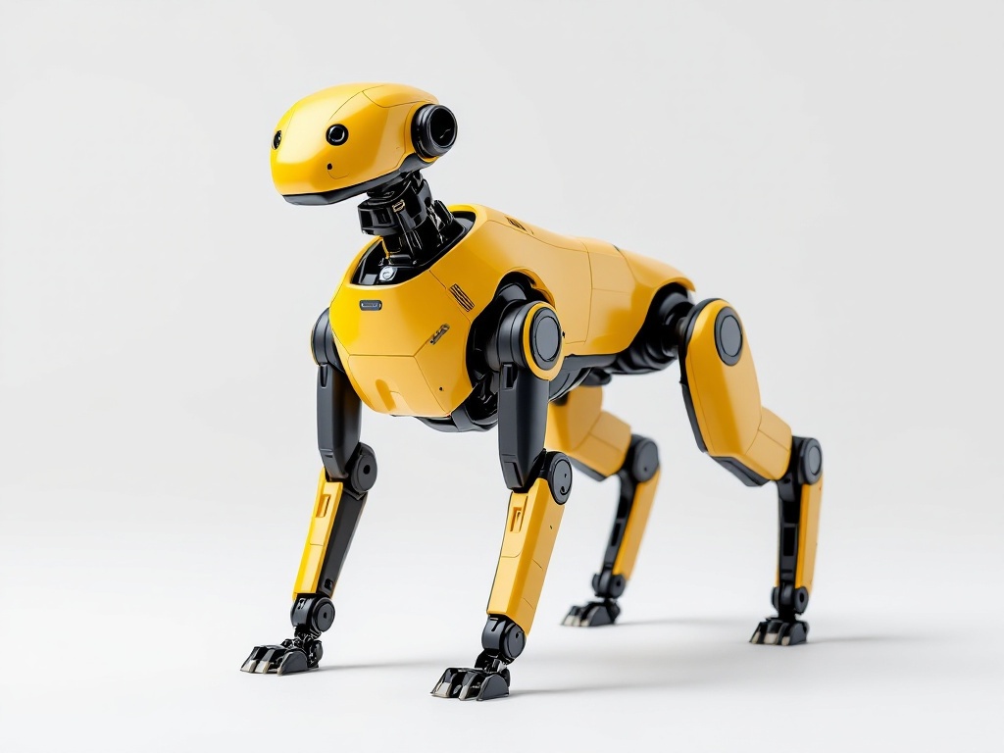
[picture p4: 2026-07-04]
ref/flux_3q_b.jpg

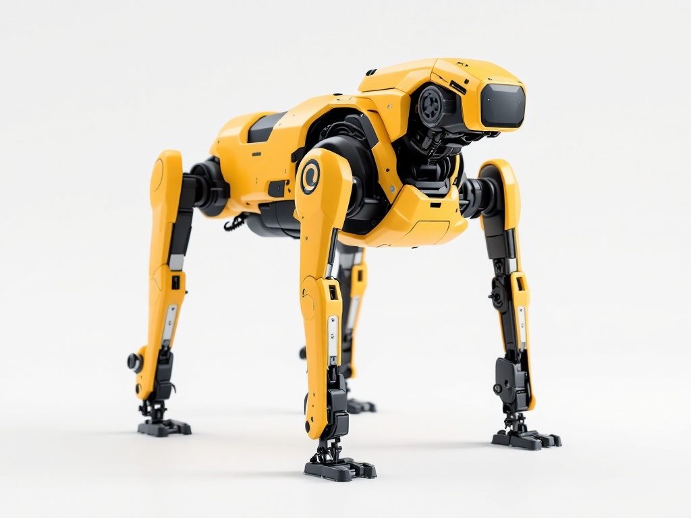
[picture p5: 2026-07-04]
ref/flux_3q_a.jpg

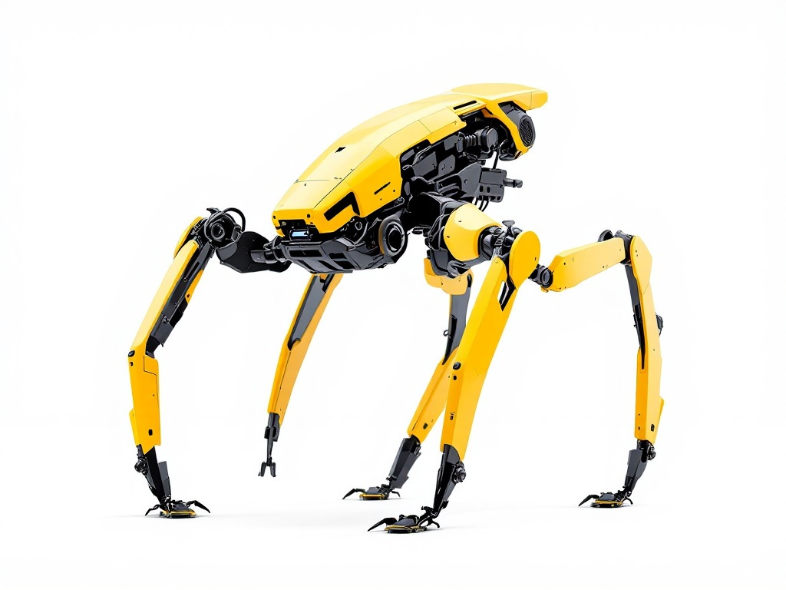
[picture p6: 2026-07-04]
ref/flux_side_a.jpg

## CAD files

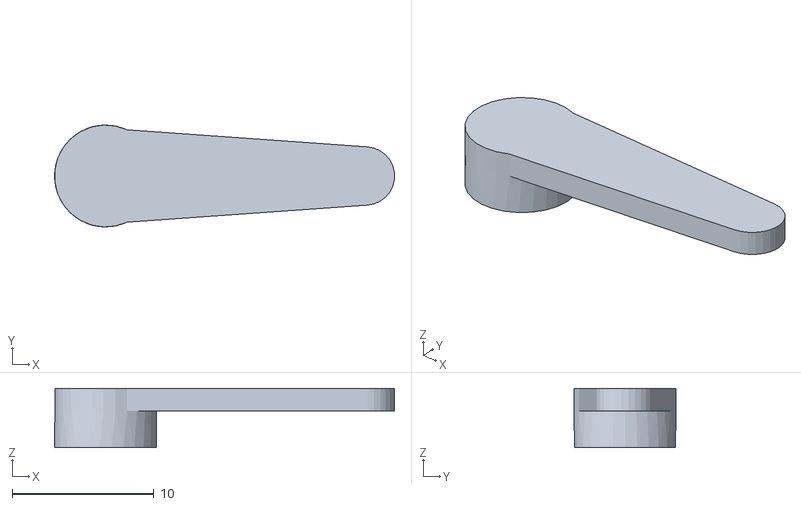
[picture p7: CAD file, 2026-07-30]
servos/hornarm.stl
24.0 x 7.20 x 4.20

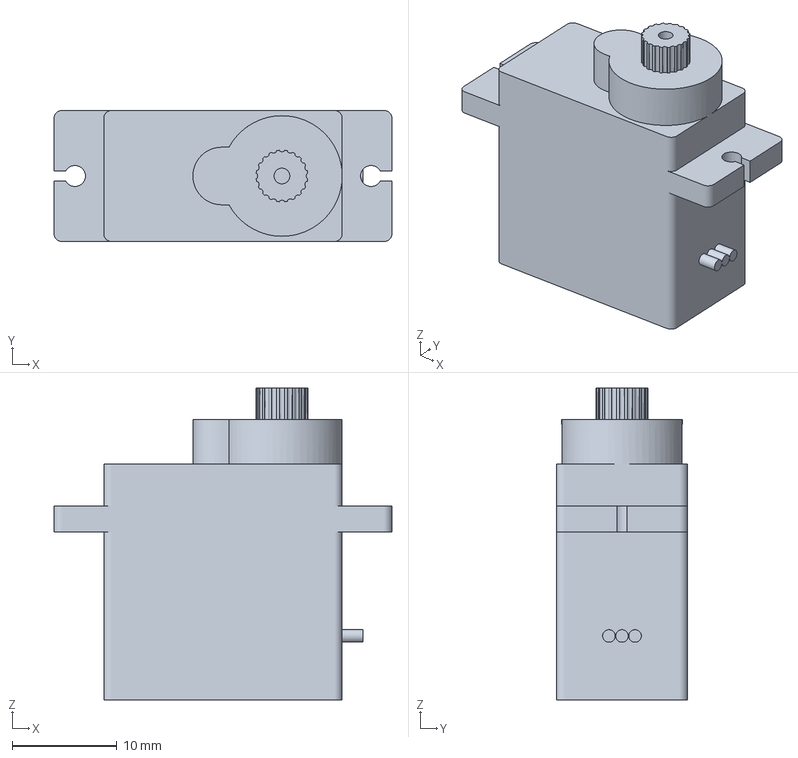
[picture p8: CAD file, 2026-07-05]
SG90-Servo.3mf
32.2 x 12.5 x 29.8 mm

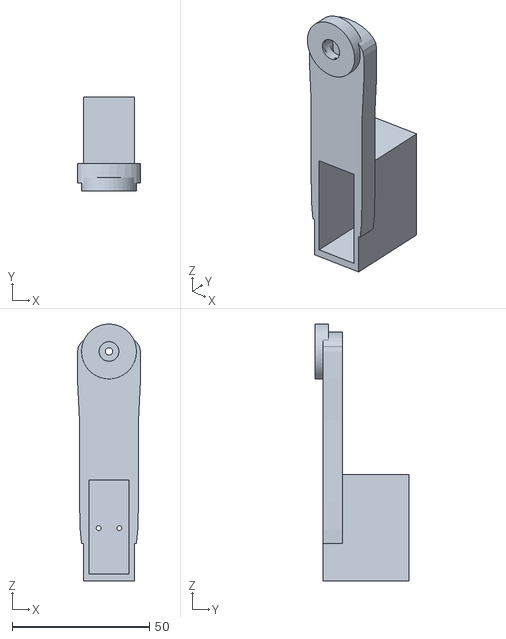
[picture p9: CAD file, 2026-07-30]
stl/sm3sg90_v9_femur.stl
23.0 x 34.3 x 93.6

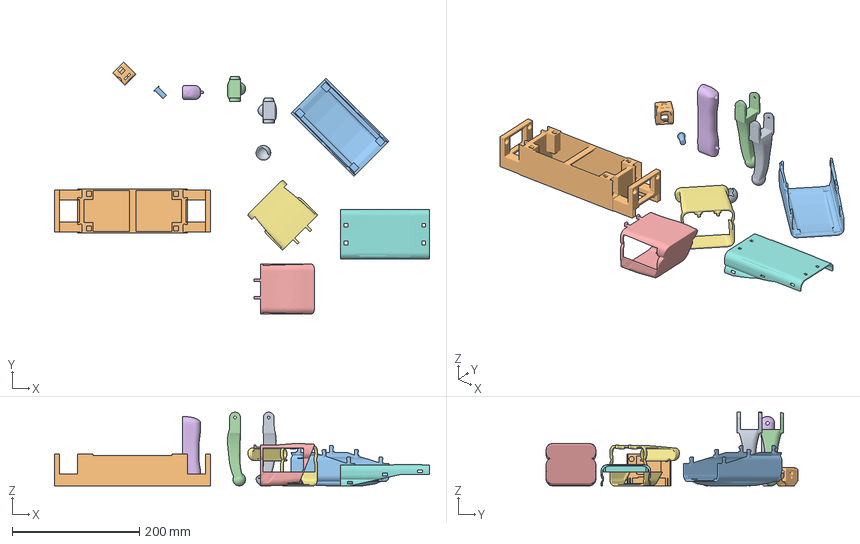
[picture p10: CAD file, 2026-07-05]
robodog.3mf
588.3 x 394.9 x 115.7 mm
sm3sg90_tibia.stl
sm3sg90_frame.stl
sm3sg90_body_bottom_tub.stl
sm3sg90_tibia_rear.stl
sm3sg90_body_head.stl
sm3sg90_femur.stl
sm3sg90_body_rump.stl
sm3sg90_body_top_lid.stl
sm3sg90_boot_TPU.stl
sm3sg90_coxa.stl
sm3sg90_pin.stl

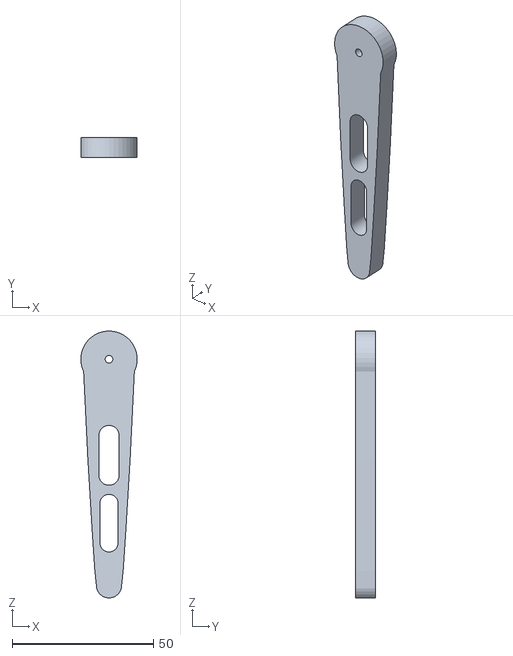
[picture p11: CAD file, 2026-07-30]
stl/sm3sg90_v9_tibia.stl
20.0 x 7.00 x 94.5

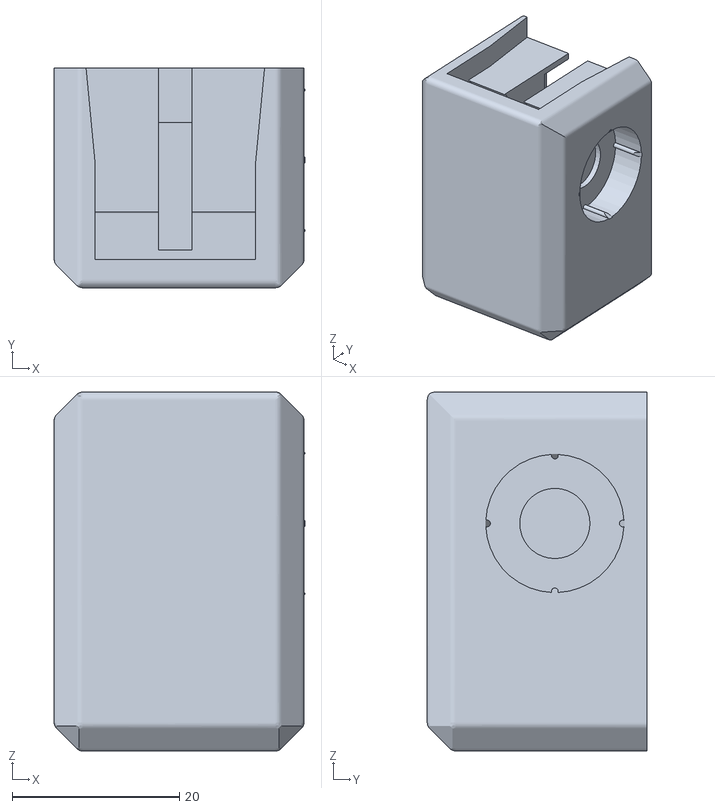
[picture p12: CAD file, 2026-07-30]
stl/sm3sg90_coxa.stl
30.0 x 26.3 x 43.0

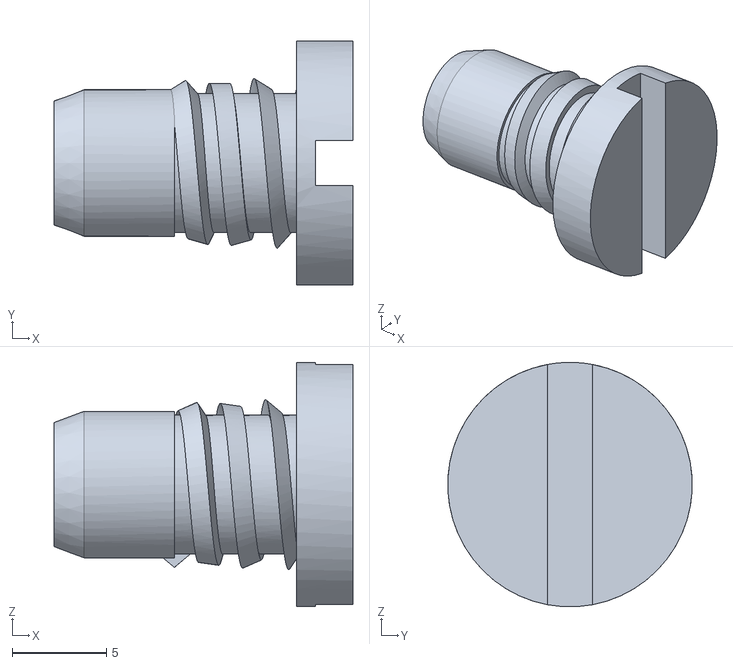
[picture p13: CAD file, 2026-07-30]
stl/sm3sg90_pin.stl
15.9 x 13.0 x 13.0

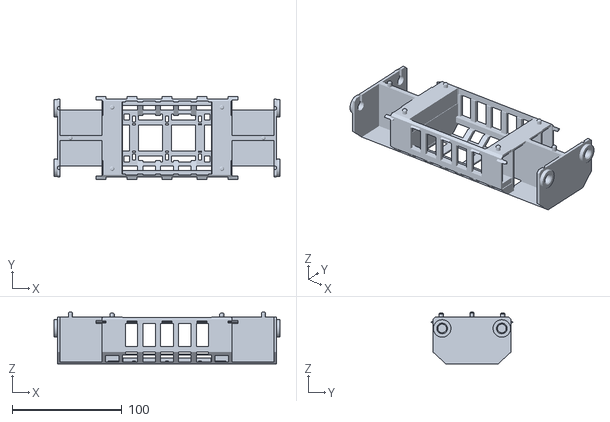
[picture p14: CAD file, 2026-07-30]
stl/sm3sg90_v9_frame.stl
206.0 x 75.4 x 47.4

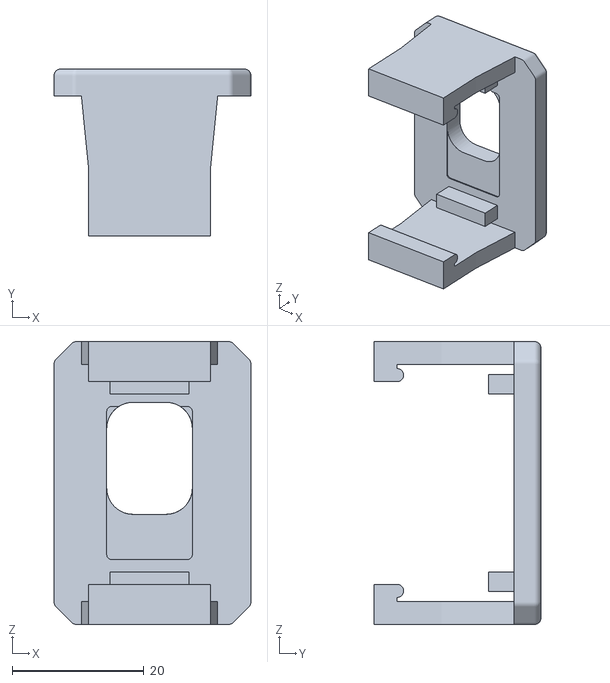
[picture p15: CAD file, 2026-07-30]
stl/sm3sg90_coxa_cover.stl
29.9 x 25.4 x 43.0

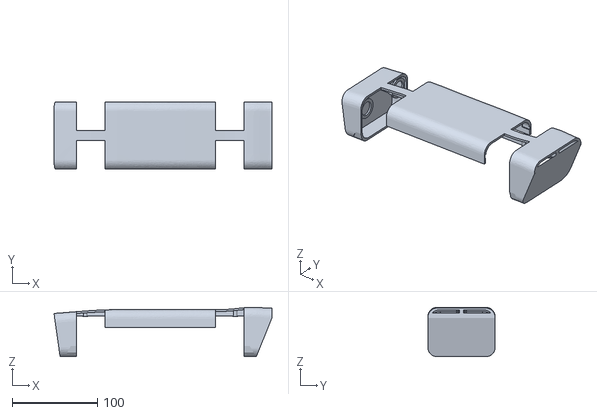
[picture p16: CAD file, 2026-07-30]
stl/sm3sg90_body.stl
255.9 x 79.0 x 58.0

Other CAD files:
stl/sm3sg90_v9_femur_mir.stl
stl/sm3sg90_v9_tibia_mir.stl
stl/sm3sg90_coxa_mir.stl
stl/sm3sg90_coxa_cover_mir.stl
SG90-Servo.stl

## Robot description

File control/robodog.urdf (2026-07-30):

<?xml version="1.0"?>
<robot name="robodog">
  <link name="base_link">
    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
    <inertial>
      <origin xyz="0.000044 -0.000000 -0.002033"/>
      <mass value="3.563629e-02"/>
      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
    </inertial>
  </link>
  <link name="fl_coxa">
    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
    <inertial>
      <origin xyz="0.082858 0.000053 -0.006310"/>
      <mass value="1.055894e-02"/>
      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
    </inertial>
  </link>
  <link name="fl_femur">
    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
    <inertial>
      <origin xyz="-0.000000 0.055190 -0.040824"/>
      <mass value="6.769587e-03"/>
      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
    </inertial>
  </link>
  <link name="fl_tibia">
    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
    <inertial>
      <origin xyz="-0.000000 0.041452 -0.032849"/>
      <mass value="2.671392e-03"/>
      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
    </inertial>
  </link>
  <joint name="fl_splay" type="revolute">
    <parent link="base_link"/>
    <child link="fl_coxa"/>
    <origin xyz="0.000000 0.027200 0.010398"/>
    <axis xyz="1 0 0"/>
    <limit lower="-0.7854" upper="0.7854" effort="2.0" velocity="8.0"/>
  </joint>
  <joint name="fl_pitch" type="revolute">
    <parent link="fl_coxa"/>
    <child link="fl_femur"/>
    <origin xyz="0.082650 -0.027200 0.000000"/>
    <axis xyz="0 1 0"/>
    <limit lower="-1.5708" upper="1.5708" effort="2.0" velocity="8.0"/>
  </joint>
  <joint name="fl_knee" type="revolute">
    <parent link="fl_femur"/>
    <child link="fl_tibia"/>
    <origin xyz="0.000000 0.000000 -0.070000"/>
    <axis xyz="0 1 0"/>
    <limit lower="-1.2217" upper="1.2217" effort="2.0" velocity="8.0"/>
  </joint>
  <link name="fr_coxa">
    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
    <inertial>
      <origin xyz="0.082858 -0.000053 -0.006310"/>
      <mass value="1.055894e-02"/>
      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
    </inertial>
  </link>
  <link name="fr_femur">
    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
    <inertial>
      <origin xyz="0.000000 -0.055189 -0.040822"/>
      <mass value="6.769908e-03"/>
      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
    </inertial>
  </link>
  <link name="fr_tibia">
    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
    <inertial>
      <origin xyz="0.000000 -0.041452 -0.032837"/>
      <mass value="2.672339e-03"/>
      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
    </inertial>
  </link>
  <joint name="fr_splay" type="revolute">
    <parent link="base_link"/>
    <child link="fr_coxa"/>
    <origin xyz="0.000000 -0.027200 0.010398"/>
    <axis xyz="1 0 0"/>
    <limit lower="-0.7854" upper="0.7854" effort="2.0" velocity="8.0"/>
  </joint>
  <joint name="fr_pitch" type="revolute">
    <parent link="fr_coxa"/>
    <child link="fr_femur"/>
    <origin xyz="0.082650 0.027200 0.000000"/>
    <axis xyz="0 1 0"/>
    <limit lower="-1.5708" upper="1.5708" effort="2.0" velocity="8.0"/>
  </joint>
  <joint name="fr_knee" type="revolute">
    <parent link="fr_femur"/>
    <child link="fr_tibia"/>
    <origin xyz="0.000000 0.000000 -0.070000"/>
    <axis xyz="0 1 0"/>
    <limit lower="-1.2217" upper="1.2217" effort="2.0" velocity="8.0"/>
  </joint>
  <link name="rl_coxa">
    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
    <inertial>
      <origin xyz="-0.082858 0.000053 -0.006310"/>
      <mass value="1.055894e-02"/>
      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
    </inertial>
  </link>
  <link name="rl_femur">
    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
    <inertial>
      <origin xyz="-0.000000 0.055189 -0.040822"/>
      <mass value="6.769908e-03"/>
      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
    </inertial>
  </link>
  <link name="rl_tibia">
    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
    <inertial>
      <origin xyz="-0.000000 0.041452 -0.032837"/>
      <mass value="2.672339e-03"/>
      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
    </inertial>
  </link>
  <joint name="rl_splay" type="revolute">
    <parent link="base_link"/>
    <child link="rl_coxa"/>
    <origin xyz="0.000000 0.027200 0.010398"/>
    <axis xyz="1 0 0"/>
    <limit lower="-0.7854" upper="0.7854" effort="2.0" velocity="8.0"/>
  </joint>
  <joint name="rl_pitch" type="revolute">
    <parent link="rl_coxa"/>
    <child link="rl_femur"/>
    <origin xyz="-0.082650 -0.027200 0.000000"/>
    <axis xyz="0 1 0"/>
    <limit lower="-1.5708" upper="1.5708" effort="2.0" velocity="8.0"/>
  </joint>
  <joint name="rl_knee" type="revolute">
    <parent link="rl_femur"/>
    <child link="rl_tibia"/>
    <origin xyz="0.000000 0.000000 -0.070000"/>
    <axis xyz="0 1 0"/>
    <limit lower="-1.2217" upper="1.2217" effort="2.0" velocity="8.0"/>
  </joint>
  <link name="rr_coxa">
    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
    <inertial>
      <origin xyz="-0.082858 -0.000053 -0.006310"/>
      <mass value="1.055894e-02"/>
      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
    </inertial>
  </link>
  <link name="rr_femur">
    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
    <inertial>
      <origin xyz="0.000000 -0.055190 -0.040824"/>
      <mass value="6.769587e-03"/>
      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
    </inertial>
  </link>
  <link name="rr_tibia">
    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
    <inertial>
      <origin xyz="0.000000 -0.041452 -0.032849"/>
      <mass value="2.671392e-03"/>
      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
    </inertial>
  </link>
  <joint name="rr_splay" type="revolute">
    <parent link="base_link"/>
    <child link="rr_coxa"/>
    <origin xyz="0.000000 -0.027200 0.010398"/>
    <axis xyz="1 0 0"/>
    <limit lower="-0.7854" upper="0.7854" effort="2.0" velocity="8.0"/>
  </joint>
  <joint name="rr_pitch" type="revolute">
    <parent link="rr_coxa"/>
    <child link="rr_femur"/>
    <origin xyz="-0.082650 0.027200 0.000000"/>
    <axis xyz="0 1 0"/>
    <limit lower="-1.5708" upper="1.5708" effort="2.0" velocity="8.0"/>
  </joint>
  <joint name="rr_knee" type="revolute">
    <parent link="rr_femur"/>
    <child link="rr_tibia"/>
    <origin xyz="0.000000 0.000000 -0.070000"/>
    <axis xyz="0 1 0"/>
    <limit lower="-1.2217" upper="1.2217" effort="2.0" velocity="8.0"/>
  </joint>
</robot>

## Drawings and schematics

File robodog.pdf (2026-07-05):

# ROBO

D

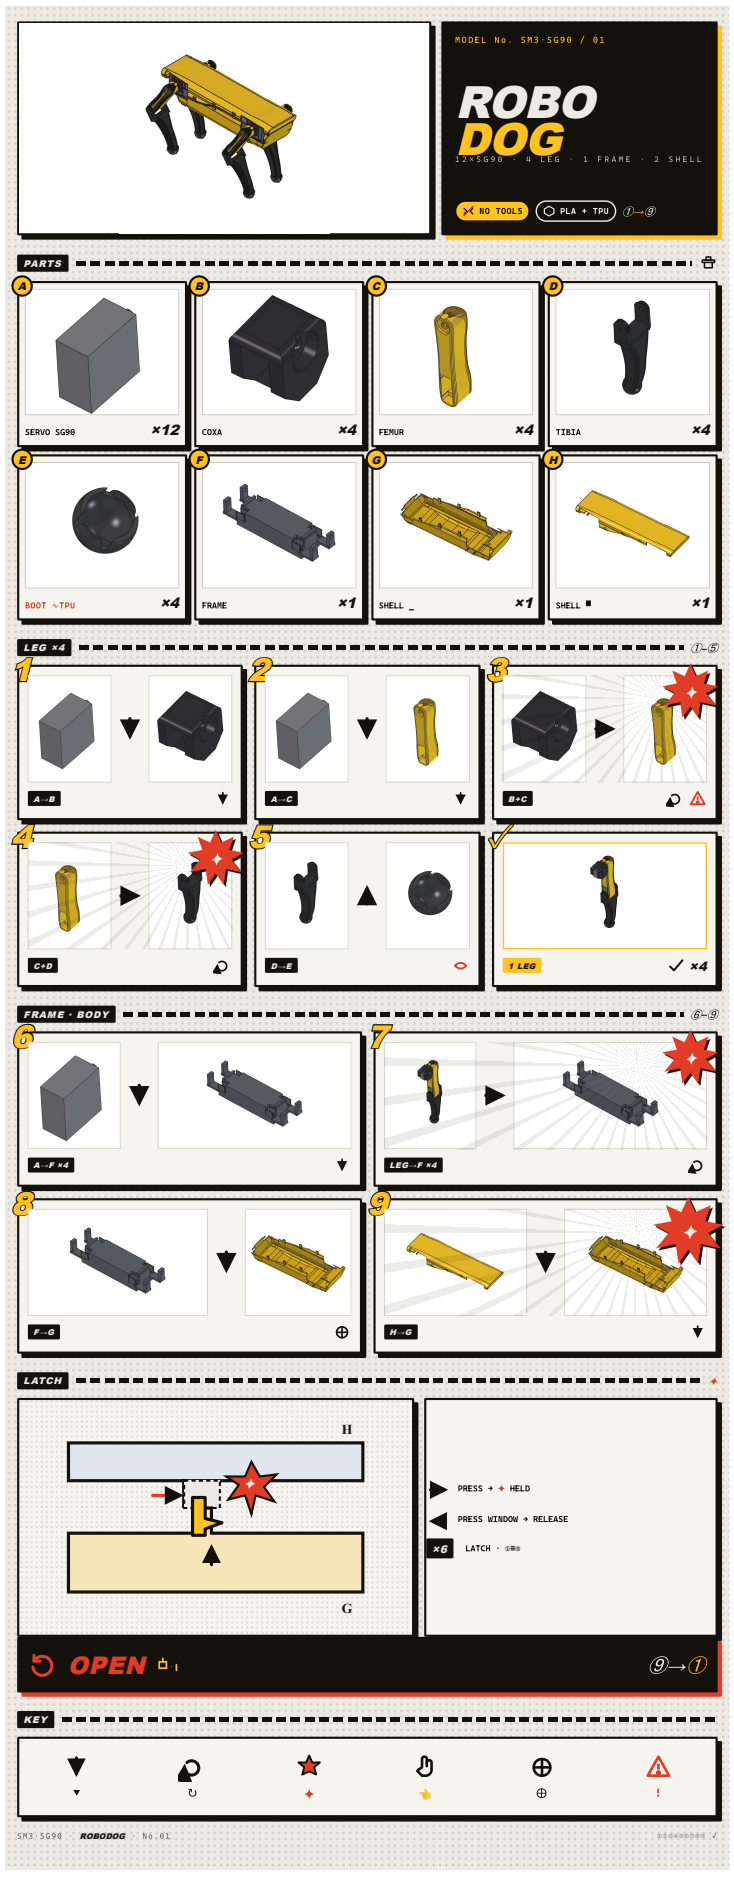
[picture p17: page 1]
NO TOOLS; PLA + TPU; PARTS; LEG ×4; FRAME · BODY; LATCH; OPEN; KEY; · ROBODOG ·; SERVO SG90; COXA; FEMUR; TIBIA; BOOT ∿TPU; FRAME; SHELL ▁; SHELL ▀; 1 LEG; LEG→F ×4; PRESS → ✦ HELD; ×6 LATCH · ①≡⑨

PRESS WINDOW → RELEASE

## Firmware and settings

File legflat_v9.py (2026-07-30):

# legflat_v9.py == DIRECT-DRIVE knee (no linkage), scaled ~0.82x: femur 70 / tibia 80. Lightest-possible bones.
#   servo3 lies flat along the LOWER FEMUR (long axis down the thigh), output spline pokes laterally INBOARD (-Y) at
#   the knee K (servo FLIPPED 2026-07-22; body stays outboard); the tibia bolts straight to its horn. 1:1. Drops v8's
#   crank/pushrod/kneecap-lever/688/O8-pin.
#   Knee load carried by the servo output shaft, SINGLE-SHEAR -> MG90S (metal gears + output bushing) is MANDATORY
#   at the knee, not optional (user decision 2026-07-27). A printed inboard double-shear stub was built and dropped:
#   the audit flagged the PLA-on-PLA journal + thin bridges as a fresh failure point, and single-shear on MG90S is
#   the lighter, simpler load path. The tibia bolts to the MG90S horn; the M2 centre screw carries pull-off.
#   Y-LAYERS (inboard->outboard): tibia 28.7-35.7 | servo3 spline 34-36 on the knee | femur plate 36-43 |
#     servo3 tab flats -> Y45 | servo3 body hangs outboard to ~64. Servo body drops THROUGH a plate slot,
#     the two mounting tabs seat on offset flats (M2 self-tap), output spline pokes INBOARD to the tibia.
import FreeCAD as App, FreeCADGui as Gui, Mesh, Part, MeshPart, math, traceback
v=App.Vector; X,Y,Z=v(1,0,0),v(0,1,0),v(0,0,1)
def box(a,b,c,p): return Part.makeBox(a,b,c,p)
def cyl(r,h,p): return Part.makeCylinder(r,h,p,Y)
def disc(r,p,y0,yl): return Part.makeCylinder(r,yl,v(p[0],y0,p[1]),Y)
def plate(pts,y0,yl):
    w=Part.makePolygon([v(x,y0,z) for (x,z) in pts]+[v(pts[0][0],y0,pts[0][1])])
    return Part.Face(w).extrude(v(0,yl,0))
def biggest(s): q=s.Solids; return max(q,key=lambda k:k.Volume) if q else s
LOG=[]
def log(s): LOG.append(str(s))
try:
    XC=106.0; HIPZ=10.0; KZ=-60.0; TOEZ=-140.0        # femur 70, tibia 80
    BONE=7.0
    FIY0,FIY1=36.0,43.0            # femur inboard plate (7mm), hip flange sits inboard of this
    K=(XC,KZ)
    # ---- servo horn RECEIVER: 3 modes (mesh / round / arm) via horns.py (user 2026-07-28) ----
    if 'HORN_MODE' not in globals():
        import sys as _sys
        HORN_MODE='embed'
        for _a in _sys.argv[1:]:
            if _a.startswith('--horn='): HORN_MODE=_a.split('=',1)[1].strip().lower()
    exec(open(r"C:/ultrafish/robodog/horns.py").read())            # -> MODES, resolve, horn_void, ...  (exec, not import: no stale cache)
    CANON='arm'                                                    # leg canonical (LEG_SPEC: the STRONG joint); keeps the sm3sg90_v9_* names
    PRIMARY=resolve(HORN_MODE,CANON)
    RND_BONE=14.0                                                  # round-disc OD for the bones -- fits the O20 boss with a roof (coxa keeps O20)
    def slot(cx,z1,z2,r,y0,yl):                   # racetrack lightening tool (z1>z2), full bone thickness
        return box(2*r,yl,z1-z2,v(cx-r,y0,z2)).fuse(disc(r,(cx,z1),y0,yl)).fuse(disc(r,(cx,z2),y0,yl))
    # ---- servo3 mesh: long axis DOWN the thigh (Z), output spline INBOARD (-Y) at the knee (body stays outboard) ----
    def servo_base(clr):
        m=Mesh.Mesh(); m.read(r"C:/ultrafish/robodog/SG90-Servo.stl"); c=m.BoundBox.Center
        m.translate(-c.x,-c.y,-c.z)
        # anisotropic clearance = add exactly 2*clr to EACH native axis (0.5/side). Divide by the axis's OWN
        # length (not hardcoded body dims -- the mesh's native axes are {tabspan32.2, tall29.8, thin12.5}, so a
        # fixed {22.8,12.5,22.5} set landed the width divisor on the tall axis and under-clearanced the thin
        # slot axis to 0.28/side -- audit 2026-07-27). Self-correcting per axis.
        bb=m.BoundBox
        g=App.Matrix(); g.A11=1+2*clr/bb.XLength; g.A22=1+2*clr/bb.YLength; g.A33=1+2*clr/bb.ZLength
        m.transform(g); s=Part.Shape(); s.makeShapeFromMesh(m.Topology,0.05); return Part.makeSolid(s)
    # servo3 FLIPPED (user 2026-07-22): OUTPUT points INBOARD (-Y) so the tibia tucks on the INSIDE of the femur,
    # against its inner face; only the servo body sticks out outboard. Boss lands on the knee axis (drivable).
    BOSS_DZ=-5.62    # output-boss Z-offset from the servo centre in the flipped frame (measured off SG90-Servo.stl)
    def place_servo(clr):
        s=servo_base(clr)
        s.rotate(v(0,0,0),Y,90.0)          # output axis -> Y (boss on +Y), long axis -> Z (down thigh), thin -> X
        s.rotate(v(0,0,0),Z,180.0)         # FLIP: boss to -Y (inboard, tibia side); long axis stays down Z
        b=s.BoundBox
        # spline tip (bbox YMin) lands 2mm inboard of the femur inner face (FIY0) -> the spline reaches just inside
        # the femur and the tibia grips it there; boss (Z-offset BOSS_DZ from centre) lands ON the knee axis KZ.
        s.translate(v(XC-b.Center.x, (FIY0-2.0)-b.YMin, (KZ-BOSS_DZ)-b.Center.z))
        return s
    SVc=place_servo(0.5); SV=place_servo(0.0); sb=SV.BoundBox
    log("servo3 X[%.1f,%.1f] Y[%.1f,%.1f] Z[%.1f,%.1f]  (output -Y INBOARD; thin=%.1f tall=%.1f long=%.1f)"%(
        sb.XMin,sb.XMax,sb.YMin,sb.YMax,sb.ZMin,sb.ZMax,sb.XLength,sb.YLength,sb.ZLength))
    TIY1=FIY0-0.3; TIY0=TIY1-BONE                     # tibia INBOARD, outboard face 0.3 clr inside the femur inner face (max spline grip)
    log("tibia Y[%.1f,%.1f] (inboard, close to femur inner face %.1f)  servo body outboard to %.1f  leg width %.1f"%(
        TIY0,TIY1,FIY0,sb.YMax,sb.YMax-TIY0))
    # ============================ FEMUR (inboard plate, hip -> knee + servo3 SLIDE-IN SLOT) ============================
    def servo_mount(fe):
        # servo3 CLOSED POCKET, CAPPED TOP (user 2026-07-28): the housing wraps the servo BODY on +/-X, outboard +Y,
        # bottom -Z AND the top +Z (now CAPPED). The ONLY opening is the INBOARD -Y (spline/tibia) face: the servo
        # slides in LATERALLY from there, its output spline pokes out -Y to the tibia, and the tibia + M2 centre screw
        # cap the -Y opening = retention. Above the servo top the femur reverts to SOLID plate up to the hip. Walls
        # 2.0mm (W-CLR). (Was an open-+Z slide-DOWN channel; the audit reinforced the walls, this re-aims the insert.)
        b=SVc.BoundBox; x0,x1,y0,y1,z0,z1=b.XMin,b.XMax,b.YMin,b.YMax,b.ZMin,b.ZMax
        W=2.6; CLR=0.6; ZTOP=z1+1.0; HTOP=ZTOP+2.0     # cavity top +1mm over servo; +2.0mm top CAP; -Y open full height
        fe=fe.fuse(box((x1-x0)+2*W, (y1+W)-FIY0, HTOP-(z0-W), v(x0-W, FIY0, z0-W))); fe=biggest(fe)      # HOUSING (capped +Z, open -Y)
        # body cavity OPEN on -Y across the FULL servo height z0..ZTOP: the servo -- INCLUDING its full-width bottom
        # flange/tab -- slides in LATERALLY from the -Y side; the -Z wall (z0-W..z0) is the floor it rests on. (Was
        # BODZ0=z0+4.2, which left the plate solid below the servo bottom and BLOCKED the bottom tab -- user 2026-07-28.)
        fe=fe.cut(box((x1-x0)+2*CLR, (y1-FIY0)+CLR, ZTOP-z0, v(x0-CLR, FIY0, z0)))                       # body cavity (open -Y, full height)
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

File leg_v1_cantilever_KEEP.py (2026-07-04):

# SM3-SG90 "mini Nova" — parametric leg + (SM3-derived) body, FreeCAD 1.1 Part workbench
#
# Redesign brief: SM3 rounded body + proportions @0.6 scale, SG90 servos, snap-together,
#   tuned for a 0.4 mm nozzle / 0.08 mm layers.  Two structural fixes vs SM3:
#     (1) CLOSED 6-sided servo pockets (SM3 leaves a big face open -> weak)  -> box + snap cap
#     (2) OFFSET CANTILEVER knee so the tibia folds nearly flat past the femur (lie-down pose)
#
# Run:  exec(open(r"C:/ultrafish/3dprint/sm3-sg90/build.py").read())
#
# Leg local frame: femur along +X (hip-pitch axis Y at X=0, knee axis Y at X=Lf),
#   Z = up (sagittal plane = XZ).  Joint axes = Y, so fold happens in the XZ plane.
#   Servo canonical: output shaft +Z at origin, top face at Z=0, body hangs -Z, gear end +X.

import FreeCAD as App, Part, math
from FreeCAD import Vector as v

OUT = "C:/ultrafish/3dprint/sm3-sg90"
X, Y, Z, O = v(1,0,0), v(0,1,0), v(0,0,1), v(0,0,0)
S = 0.6  # global scale of SM3 link proportions (servos are real-size, do NOT scale)

P = dict(
    # ---- SG90 envelope (real, fixed) ----
    bL=22.7, bW=12.1, bH=22.5, shaft_off=6.0, hub_d=5.4, hub_h=4.0,
    tab_span=32.0, tab_th=2.4, tab_below=4.5, wire_w=6.0, wire_h=4.5, wire_len=6.5,
    # ---- print / fit (0.4 nozzle, 0.08 layer) ----
    clr=0.25,            # servo pocket clearance per side
    wall=2.0,            # 5 perimeters @0.4 -> closed-pocket walls
    capgap=0.20,         # snap-cap fit gap
    # ---- spline coupling (heat-set metal spline + M2 screw; only hardware) ----
    insert_d=5.0, insert_h=4.5, boss_d=12.0, boss_h=6.0,
    screw_d=2.2, screw_head_d=4.4, screw_head_h=2.0,
    # ---- link lengths (~0.6 x SM3 proportions, femur:tibia ~ 1:1.08) ----
    coxa_len=30.0, femur_len=64.0, tibia_len=70.0,
    leg_y=12.0,          # slim in-plane thickness (Y) of leg shafts
    knee_gap=1.2,        # extra Y clearance, folded tibia vs femur
)


# ---------------------------------------------------------------- primitives
def sg90_cutter(clear=0.0):
    """Solid SG90 envelope; output axis at origin, shaft +Z, top face Z=0, body -Z."""
    c = clear
    L, W, H = P['bL']+2*c, P['bW']+2*c, P['bH']+2*c
    x0 = -(P['bL']-P['shaft_off']) - c
    body = Part.makeBox(L, W, H, v(x0, -W/2, -H))
    hub  = Part.makeCylinder(P['hub_d']/2+c, P['hub_h']+c, O, Z)            # output hub
    bc   = P['shaft_off'] - P['bL']/2
    Tl   = P['tab_span']+2*c
    tz   = -P['tab_below']
    tabs = Part.makeBox(Tl, W, P['tab_th']+2*c, v(bc-Tl/2, -W/2, tz-P['tab_th']-c))
    wire = Part.makeBox(P['wire_len']+c, P['wire_w']+2*c, P['wire_h']+2*c,
                        v(x0-P['wire_len'], -(P['wire_w']/2+c), -P['wire_h']/2-c))
    return body.fuse(hub).fuse(tabs).fuse(wire).removeSplitter()

def boss(at, axis, h=None):
    """Driven coupling boss (spline-insert bore + counterbored M2), base at `at`, growing along axis."""
    h = h or P['boss_h']
    b = Part.makeCylinder(P['boss_d']/2, h, at, axis)
    ins = Part.makeCylinder(P['insert_d']/2, P['insert_h']+0.01, at-axis*0.005, axis)
    shk = Part.makeCylinder(P['screw_d']/2,  h+0.02, at-axis*0.01, axis)
    hd  = Part.makeCylinder(P['screw_head_d']/2, P['screw_head_h']+0.01,
                            at+axis*(h-P['screw_head_h']), axis)
    return b.cut(ins).cut(shk).cut(hd)

def rot(s, axis, deg, ctr=O):
    s = s.copy(); s.rotate(ctr, axis, deg); return s

def bb_box(bb, wall):
    return Part.makeBox(bb.XLength+2*wall, bb.YLength+2*wall, bb.ZLength+2*wall,
                        v(bb.XMin-wall, bb.YMin-wall, bb.ZMin-wall))

def safe_fillet(s, r, minlen=None):
    minlen = minlen or 2.2*r
    try:
        es = [e for e in s.Edges if e.Length > minlen]
        return s.makeFillet(r, es) if es else s
    except Exception:
        return s


# ---------------------------------------------------------------- closed pocket
def place_knee_servo(Lf, clear=0.0):
    """Knee servo (servo 3) at the femur distal end: shaft +Y (outboard), body -Y (inboard)."""
    c = rot(sg90_cutter(clear), X, -90)      # shaft +Z -> +Y, body -Z -> -Y
    c.translate(v(Lf, 0, 0))                 # shaft axis through knee point (Lf,0,0)
    return c

def closed_pocket(Lf):
    """Return (housing_solid, cavity_cutter, cap_solid) for the knee servo.
    Housing fully encloses the servo (all 6 faces walled) EXCEPT a drop-in opening on +Z,
    which a snap cap closes -> the SM3 'open side' is gone.  Shaft exits a hole in +Y wall."""
    sv  = place_knee_servo(Lf, 0.0)
    cav = place_knee_servo(Lf, P['clr'])
    bb  = sv.BoundBox
    w   = P['wall']
    house = bb_box(bb, w)
    # drop-in opening on +Z (top): remove the top wall over the cavity footprint
    topcut = Part.makeBox(bb.XLength+P['clr']*2, bb.YLength+P['clr']*2, w+0.2,
                          v(bb.XMin-P['clr'], bb.YMin-P['clr'], bb.ZMax))
    # boss clearance hole through +Y wall (driven boss passes through to seat on servo top face)
    hub = Part.makeCylinder(P['boss_d']/2+P['clr'], w+1.0, v(Lf,0,0), Y).translate(v(0,bb.YMax-0.5,0))
    house = house.cut(cav).cut(topcut).cut(hub)
    # snap cap: plate that drops into the +Z opening, with a lip
    cap = Part.makeBox(bb.XLength+P['clr']*2-2*P['capgap'], bb.YLength+P['clr']*2-2*P['capgap'], w,
                       v(bb.XMin-P['clr']+P['capgap'], bb.YMin-P['clr']+P['capgap'], bb.ZMax-w))
    lip = Part.makeBox(bb.XLength+2*w-0.4, bb.YLength+2*w-0.4, w*0.6,
                       v(bb.XMin-w+0.2, bb.YMin-w+0.2, bb.ZMax))
    cap = cap.fuse(lip).removeSplitter()
    return house, cav, cap


# ---------------------------------------------------------------- leg parts
def make_femur(side=1):
    """Flat-ish femur in XZ plane: proximal coupling boss (to hip-pitch servo 2) at X=0,
    slim shaft, knee servo housing at distal X=Lf.  side=+1 left, -1 right (mirror Y)."""
    Lf = P['femur_len']
    house, cav, cap = closed_pocket(Lf)
    bb = place_knee_servo(Lf, 0.0).BoundBox
    wo = bb.YMax + P['wall']            # femur +Y wall outer face
    # slim shaft beam from proximal to the knee housing; +Y face kept inboard of the tibia plane
    bh = P['bH'] + 2*P['wall']          # ~ knee housing height in Z
    y_in = -(P['leg_y']/2 + P['wall'])  # inboard face (toward servo body)
    beam = Part.makeBox(Lf+6, wo - y_in, bh*0.78, v(-3, y_in, -bh*0.30))
    beam = safe_fillet(beam, 3.0)
    fem = house.fuse(beam).removeSplitter().cut(cav)
    # clear the +Y knee coupling zone so the tibia boss seats on the servo top face (Y=0)
    bc = Part.makeCylinder(P['boss_d']/2+P['clr'], wo+2, v(Lf, -1, 0), Y)
    fem = fem.cut(bc)
    # proximal coupling boss: mounts on coxa's hip-pitch servo shaft (+Y from coxa) -> boss faces -Y
    pb = boss(v(0, -(P['leg_y']/2+P['wall']), 0), Y*-1)
    fem = fem.fuse(pb).removeSplitter()
    if side < 0:
        fem = fem.mirror(O, Y); cap = cap.mirror(O, Y)
    return fem, cap
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

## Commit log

2026-07-04 print ready?
    [sm3sg90_body_bottom_tub.stl, sm3sg90_body_top_lid.stl, sm3sg90_boot.stl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]
2026-07-04 robodog.md: refresh restart doc for handoff
    Audit + edit for a clean session handoff: rewrite the stale "Resume
    here" and "Files" sections (they still pointed at dog.py / leg4-7 and
    the wrong working dir) to the current canonical scripts (dog13.py,
    bodyview.py, assembly.py, frameview.py, pamphlet.*), the 7-STL
    deliverable, and the yellow-body/black-leg colorway; add a close-out
    Update covering the cantilever latches, frame locating keys, colorway,
    and manga pamphlet, plus the single-shell invariant and next steps.
2026-07-05 v29 slicer-ready mechanics + all-Python control/sim stack
    CAD (dog13.py v29 + exporters):
    - Splay-pin square heads recessed in keyed pillar sockets + vertical
    retention clips; frame holds 245mm (ABS margin), pin^frame=0.
    - L/R mirror STLs for the chiral coxa/femur/tibia; printable dummy bearings.
    - Servo pockets model-cut from the real SG90 mesh + nub wire slots.
    - Pre-print STL repair: all 17 STLs verified watertight/manifold/
    self-intersection-free (fixSelfIntersections checked on-disk).
    - Covers re-fit to the tub frame; dry-run test-fit assembles (57 parts).
    control/ - new all-Python control + PyBullet sim, generated from the CAD:
    - kinematics.py: per-leg 3-DOF FK/IK (FK matches PyBu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
    [SG90-Servo.3mf, SG90-Servo.stl, dog13.FCStd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]
2026-07-07 coxa: subtractive-from-block redesign + slicer-ready coxa print set
    coxablock.py (new): coxa cut from a solid block — servo pocket, tab channel,
    wire slot, splay-bearing cup (crush ribs + +X press lead-in taper), print-in-
    place horn chamber, and a Ø8.4 blind pin-tip relief behind the 688.
    - cover snap = mirrored cantilever finger -> 90deg leg -> rounded nub; nub
    recess + uniform relief on the coxa; servo retained by a cover retainer tab
    - femur insert (RING): rounded bullnose friction ridge, press-fit into the cover
    - STL export block writes sm3sg90_coxa{,_cover,_insert}.stl (single solids);
    retires old dog13 sm3sg90_coxa_mir + stale body .3mf's
    - robodog.md: add a 3D-printing secti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
    [sm3sg90_body.3mf, sm3sg90_body_bottom_tub.3mf, sm3sg90_coxa.stl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]
2026-07-07 frame: subtractive-from-block redesign (frameblock.py, WIP)
    Sibling of coxablock.py: frame cut from a solid 245x68x40 block from the top.
    - coxa swing pockets x4 (coxa bbox grown in the Y,Z splay plane, breaking past
    the outboard wall for free splay)
    - servo0 (hip-yaw) slots x4, top-down; wider tabs land on a ledge so servo+coxa
    push in; block top = servo0 tab top (tab flush with the block top)
    Execs dog13.py for the live canonical parts (SH/servo0/servo1/SP/tf).
    Open: electronics cavity, then STL export.
2026-07-11 coxa: even chamfers + bearing-side bottom + boolean-robust finish
    coxablock.py refinement since the block redesign: chunky flush pry-off
    clips (validity-guarded fillets), EXI-S1123-clearing rounded-rect cover
    opening, top-hat RING thrust washer, and an even CHAMF=3.0/ROUND=1.0
    exterior finish via a shared guarded edge_op helper — plus a bearing-side
    bottom catch-up chamfer so the whole bottom perimeter matches. COXA/CLIP/
    RING all valid single solids; re-exported the 3 coxa STLs (2460/1604/582).
    robodog.md: new Update documenting the subtractive-from-block coxa/frame
    phase. .gitignore: exclude the large servo-scan / AI-asset / FreeCAD-native
    / slicer-intermediate scratch.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
    [sm3sg90_coxa.stl, sm3sg90_coxa_cover.stl, sm3sg90_coxa_insert.stl]
2026-07-29 v9: one-piece snap-on body + frame lighten/stiffen
    part_body.py: NEW one-piece cosmetic canopy (sm3sg90_body.stl) - scaled bodyview silhouette, open-belly trunk, head/rump wrap under the keel, form-fit hip openings (shell^leg 0), snaps onto a frame rim-cap bead via 6 leaf fingers; watertight, 1 component.
    framemin.py: lightened 122->102g (under-servo/rim/floor cuts), mid-span rib-posts unified to 5mm + buttress feet + substantial front-to-back cross-rib, + snap-body retention bead; watertight 110g, leg-vs-frame/coxa gates 0.00.
    robodog.md: current-state handoff Update.
    [sm3sg90_body.stl, sm3sg90_v9_frame.stl]
2026-07-30 v9 canopy: single-feature caps, snaps, screw-in pin + repo cleanup
    Body (part_body.py):
    - head/rump rebuilt as ONE tall loft (dropped dome+skirt+keel-chamfer that read
    as two stacked lobes) -> each cap a single smooth feature; belly leg relief
    - spine stiffener rib under the crown strips (T-beam) tying head-trunk-rump
    - snaps: lateral detent nubs + alignment posts + central-wall pegs into the
    spine rib + collar grip rings on the head/rump caps (wall pockets/cups to match)
    Frame (framemin.py):
    - retention nubs, alignment posts + central-wall pegs (removeSplitter-per-fuse
    to survive the truss-window seam)
    - printed screw-in splay pin: O7.8 pilot + P2.0 thread mating the collar bore +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
    [dog13.FCStd, robodog.urdf, sm3sg90_body.stl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]
2026-07-30 arm horn: blade 1.7mm thick, flush with the hub top
    User-measured correction. horns.py arm mode: ARM_T 1.6->1.7, and the arm slot
    moved from the hub BASE to FLUSH WITH THE HUB TOP (aTop-aT..aTop). The old base
    slot left the bone solid where the real blade sits at the hub top, so the blade
    collided with bone (the tibia "poking into the cutout") -- now the hub-top arm
    region is cleared and the base is solid again. Verified on all 3 arm embeds
    (coxa splay, femur hip, tibia knee): hub-top void / hub-base solid, all parts
    watertight.
    [sm3sg90_coxa.stl, sm3sg90_coxa_mir.stl, sm3sg90_v9_femur.stl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]
2026-07-30 arm horn: embed real hornarm.stl mesh + move tibia lightening clear of the blade
    The parametric hub+slot approximation never seated the real single-arm horn, so
    embed the actual mesh instead. horns.py _arm_horn() loads servos/hornarm.stl
    (makeShapeFromMesh -> makeSolid + HFIT offset); the arm branch transforms it to
    each receiver (spline +Z -> into-part with the hub bottom offset by `floor`,
    arm +X -> -A down the bone) and cuts it, so the void IS the horn and the real
    part drops in. Verified: hip / knee / splay all seat, all parts watertight.
    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
    [hornarm.stl, sm3sg90_coxa.stl, sm3sg90_coxa_mir.stl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]
2026-07-30 docs: update README + robodog.md for the v9 first-printable-prototype state
    README rewritten (was Jul-3 stale: named deleted dog.py/leg4-7, old 6-STL set,
    wrong printer). Now documents the v9 design, the 11-STL canonical print set + qty
    table, headless build commands, key files, gotchas, and open items.
    robodog.md: fixed the "Resume here" + "Files (current)" sections (removed the
    deleted bodyview/assembly/frameview/legwork/poseview/pamphlet_render refs; 11-STL
    X1C deliverable; v9 file list), and appended the 2026-07-29..30 FIRST PRINTABLE
    PROTOTYPE update (body snaps + screw-in pin + real horn embed + repo cleanup).
